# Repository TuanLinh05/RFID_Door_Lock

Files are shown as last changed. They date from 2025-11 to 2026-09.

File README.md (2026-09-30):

# 🔐 RFID Door Lock System






**🇬🇧 English** · [🇻🇳 Tiếng Việt](#tieng-viet)

A smart door lock that opens with an **RFID card** or a **keypad password**, built on an **STM32F103C8T6** with a **custom PCB**, an I²C character LCD, voice feedback and an admin menu for managing cards and passwords.

**Course project – Embedded System Design, HCM University of Technology.**
🎬 **Video demo:** [Google Drive](https://drive.google.com/drive/folders/1EJyoBcpR5TI39vi5_LgunK4Ymn7jQt8R?usp=sharing)

---

## ✨ Features

- **Two ways to unlock:** an RFID card (MFRC522, SPI) or a password on the 4×4 keypad.
- **Admin mode:** scan the admin card to change the password, add or remove cards, and view all stored cards.
- **Persistent storage:** the password and card list are saved in the STM32's **internal flash**, so they survive power loss.
- **Brute-force protection:** after 5 wrong attempts the system locks for **5 min**. It locks for **10 min** after 7 attempts and **20 min** after 9.
- **Feedback:** status on the I²C LCD and voice prompts from a **DFPlayer Mini** (granted / denied / locked / admin).
- **Relay output:** drives the electric lock (PB1) and locks again automatically after 7 s.

## 🧠 State machine

```text
IDLE ──(card / key)──▶ INPUT_PASS ──▶ ACCESS_GRANTED ──(timeout)──▶ IDLE
  │                        │
  │                        └──▶ ACCESS_DENIED ──(≥5 fails)──▶ LOCKED ──▶ IDLE
  └──(admin card)──▶ ADMIN_MENU ──▶ SET_PASS_1 → SET_PASS_2
                                 ├─▶ EDIT_CARD (add / delete)
                                 └─▶ VIEW_ALL
```

## 📂 Project structure

```text
RFID_Door_Lock/
├── Firmware/RFID_Door_Lock/   # STM32CubeIDE project
│   └── Core/
│       ├── Src/               # main.c (state machine) + CubeMX peripheral init
│       └── Lib/               # RC522, KEYPAD, LCD I2C, DFPlayer, Storage drivers
├── Hardware/                  # Altium Designer project (latest)
│   └── 01_Design/             # Schematics: MCU, POWER, RFID, LCD, Relay + PCB
├── BTL_HW_V1.0.0/             # Hardware release V1.0.0: design, 3D models, references
└── Docs/                      # Technical requirements document (PDF / DOCX)
```

## 🚀 Getting started

1. Open `Firmware/RFID_Door_Lock` in **STM32CubeIDE**, build and flash it with an ST-Link.
2. Set your admin card UID in `Core/Src/main.c`:
   ```c
   uint8_t ADMIN_UID[4] = {51, 194, 201, 27};   // replace with your card's UID
   ```
3. Copy 4 voice tracks (`0001.mp3` … `0004.mp3`: granted, denied, locked, admin) to the DFPlayer's micro-SD card.
4. Open `Hardware/01_Design/BTL_HW_V1.0.0.PrjPcb` in **Altium Designer** to view or edit the PCB.

---

## 🇻🇳 Tiếng Việt

[🇬🇧 English](#english) · **🇻🇳 Tiếng Việt**

Khóa cửa thông minh mở bằng **thẻ RFID** hoặc **mật khẩu trên bàn phím**. Hệ thống dùng **STM32F103C8T6** trên **PCB tự thiết kế**, có màn hình LCD I²C, phát âm thanh thông báo và menu quản trị để quản lý thẻ và mật khẩu.

**Bài tập lớn môn Thiết kế Hệ thống Nhúng, Trường Đại học Bách khoa – ĐHQG TP.HCM.**
🎬 **Video demo:** [Google Drive](https://drive.google.com/drive/folders/1EJyoBcpR5TI39vi5_LgunK4Ymn7jQt8R?usp=sharing)

### ✨ Tính năng

- **Hai cách mở khóa:** thẻ RFID (MFRC522, giao tiếp SPI) hoặc mật khẩu trên bàn phím 4×4.
- **Chế độ quản trị:** quét thẻ admin để đổi mật khẩu, thêm hoặc xóa thẻ, xem danh sách thẻ.
- **Lưu trữ bền vững:** mật khẩu và danh sách thẻ được lưu trong **flash nội** của STM32, không mất khi tắt nguồn.
- **Chống dò mật khẩu:** sai 5 lần thì khóa **5 phút**. Sai 7 lần khóa **10 phút**, sai 9 lần khóa **20 phút**.
- **Phản hồi:** trạng thái hiện trên LCD I²C, âm thanh từ **DFPlayer Mini** (mở cửa / từ chối / bị khóa / admin).
- **Ngõ ra relay:** điều khiển khóa điện (PB1) và tự khóa lại sau 7 giây.

Sơ đồ máy trạng thái và cấu trúc thư mục: xem phần tiếng Anh ở trên.

### 🚀 Hướng dẫn sử dụng

1. Mở `Firmware/RFID_Door_Lock` bằng **STM32CubeIDE**, build và nạp bằng ST-Link.
2. Đổi UID thẻ admin trong `Core/Src/main.c` (biến `ADMIN_UID`) thành UID thẻ của bạn.
3. Chép 4 file âm thanh (`0001.mp3` … `0004.mp3`: mở cửa, từ chối, bị khóa, admin) vào thẻ micro-SD của DFPlayer.
4. Mở `Hardware/01_Design/BTL_HW_V1.0.0.PrjPcb` bằng **Altium Designer** để xem hoặc sửa PCB.

---

<p align="center">Made by <a href="https://github.com/TuanLinh05">Vu Tuan Linh</a> · HCMUT</p>

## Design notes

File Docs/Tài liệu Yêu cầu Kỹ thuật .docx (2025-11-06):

Tài liệu Yêu cầu Kỹ thuật (Technical Requirement)

RFID_Door_Lock

1. Giới thiệu

+ Mô tả cơ bản: Hệ thống gồm 1 vi điều khiển giao tiếp với 1 RESET, 1 bàn phím, 1 relay dùng để điều khiển đóng mở cửa, 1 màn hình LCD, 1 loa thông báo, 1 mạch RFID. Hệ thống sử dụng nguồn DC 5V Adapter.

Hoạt động:
+ Khi cấp nguồn, hệ thống khởi động và hiển thị thông báo “Enter Password or Scan Card”.
+ Người dùng có thể: Nhập mật khẩu bằng bàn phím, hoặc Quẹt thẻ RFID hợp lệ để mở cửa.
+ Nếu mật khẩu hoặc thẻ hợp lệ, hệ thống: Hiển thị thông báo “Access Granted”. Phát âm thanh xác nhận.
+ Kích relay mở cửa trong thời gian định sẵn (ví dụ 5 giây).
+ Nếu nhập sai mật khẩu quá 3 lần, hệ thống sẽ: Hiển thị “System Locked – 5 Minutes”.
+ Phát âm cảnh báo qua loa. Vô hiệu hoá bàn phím trong 5 phút.

2. Requirements 2.1 Functional requirements: F-1: Hệ thống phải cho phép người dùng mở cửa bằng mật khẩu hoặc thẻ RFID hợp lệ.

F-1.1: Hệ thống đọc dữ liệu từ bàn phím ma trận (ví dụ 4×4) và nhận chuỗi số làm mật khẩu.

F-1.2: Hệ thống giao tiếp với module RFID (SPI/UART/I2C) để nhận mã thẻ.
F-1.3: Vi điều khiển so sánh mật khẩu hoặc mã RFID với dữ liệu trong EEPROM/Flash. Nếu đúng → mở cửa, nếu sai → hiển thị lỗi.

F-2: Hệ thống phải hiển thị thông tin và trạng thái hoạt động trên màn hình LCD.
F-2.1: Khi khởi động, LCD hiển thị “Enter Password or Scan Card”.
F-2.2: Khi nhập đúng, LCD hiển thị “Access Granted” trong 2 giây; khi sai, hiển thị “Wrong Password”.
F-3: Hệ thống phải có âm thanh thông báo tương ứng với từng trạng thái.
F-3.1: Khi xác thực đúng, loa phát thông báo; khi sai, phát cảnh báo.

F-4: Hệ thống phải điều khiển relay để đóng/mở cửa khi xác thực thành công.
F-4.1: Relay được kích trong 5 giây khi mở cửa; sau đó tự ngắt và trở về trạng thái chờ.
F-5: Hệ thống phải có chức năng bảo mật, giới hạn số lần nhập sai.
F-5.1: Sau 3 lần nhập sai liên tiếp, hệ thống vô hiệu hóa bàn phím 5 phút và bật cảnh báo qua loa.
F-5.2: Sau 5 phút, hệ thống tự động trở về trạng thái nhập mật khẩu ban đầu.

F-6: Hệ thống phải có khả năng đổi mật khẩu người dùng.
F-6.1: Người dùng nhấn tổ hợp phím đặc biệt (**#) để vào chế độ đổi mật khẩu. LCD hiển thị “Enter Old Password”.
F-6.2: Nếu mật khẩu cũ đúng, LCD yêu cầu nhập mật khẩu mới và xác nhận lại. Nếu trùng khớp → lưu vào EEPROM/Flash; nếu sai → báo lỗi.

F-7: Hệ thống phải hỗ trợ chế độ quản trị (Admin Mode) để quản lý thẻ RFID.
F-7.1: Khi vào chế độ Admin Mode (bằng Password_Admin hoặc thẻ master), LCD hiển thị menu: “1:Add 2:Del 3:List 4:Exit”.
F-7.2: Chức năng “Delete Card”: đọc thẻ → nếu tồn tại → xóa; nếu không → hiển thị “Not Found”.
F-7.3: Chức năng “List”: hiển thị số lượng thẻ hiện có (ví dụ “Cards: 35/50”).

F-8: Hệ thống phải lưu trữ dữ liệu bền vững.
F-8.1: Khi khởi động, hệ thống kiểm tra checksum của dữ liệu; nếu phát hiện lỗi → bỏ qua mục đó và hiển thị cảnh báo.

F-9: Hệ thống phải có nút RESET để khởi động lại toàn bộ thiết bị.

F-9.1: Khi nhấn nút RESET, toàn bộ chương trình khởi động lại và quay về trạng thái ban đầu.

F-10: Hệ thống phải hoạt động ổn định với nguồn DC 5V.

F-10.1: Vi điều khiển hoạt động ổn định trong khoảng 5V ± 5%; có mạch ổn áp và lọc nhiễu nguồn.

2.2 Non-Functional requirements:

NFR-1: Hiệu năng phản hồi: Thời gian xử lý ≤ 200 ms sau khi nhập phím hoặc quẹt thẻ.

NFR-2: An toàn dữ liệu: Dữ liệu trong EEPROM/Flash phải tồn tại sau ≥ 10⁵ chu kỳ ghi/xóa.

NFR-3: Bảo mật: Mật khẩu không hiển thị trực tiếp, chỉ hiển thị dạng ****.
NFR-4: Độ tin cậy: Tỷ lệ hoạt động đúng của hệ thống ≥ 95% sau 100 lần thử liên tiếp.

NFR-5: Khả năng phục hồi: Sau khi mất điện, hệ thống khởi động lại về trạng thái chờ mà không mất dữ liệu.

NFR-6: Thân thiện người dùng: LCD hiển thị hướng dẫn từng bước, âm thanh báo rõ ràng.

NFR-7: Giới hạn môi trường: Hoạt động trong 0–50°C, độ ẩm <85%.

NFR-8: Khả năng mở rộng: Thiết kế phần mềm theo module (Keypad, RFID, Display, EEPROM, Relay).

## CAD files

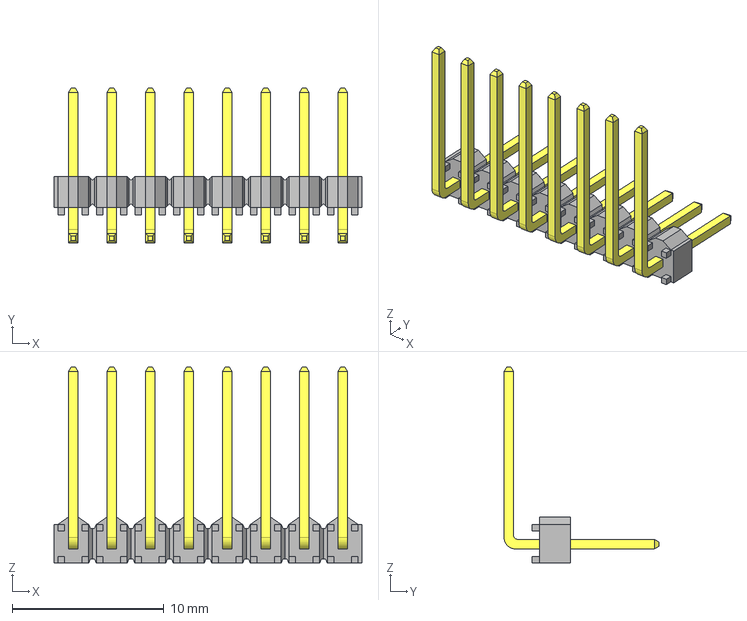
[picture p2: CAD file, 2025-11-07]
BTL_HW_V1.0.0/03_3D/TSW-108-10-S-S-RA.stp
20.3 x 10.2 x 12.9 mm
TSW-108-10-S-S-RA_body
T-1S6-10-TSW-1-10-8-RA-S

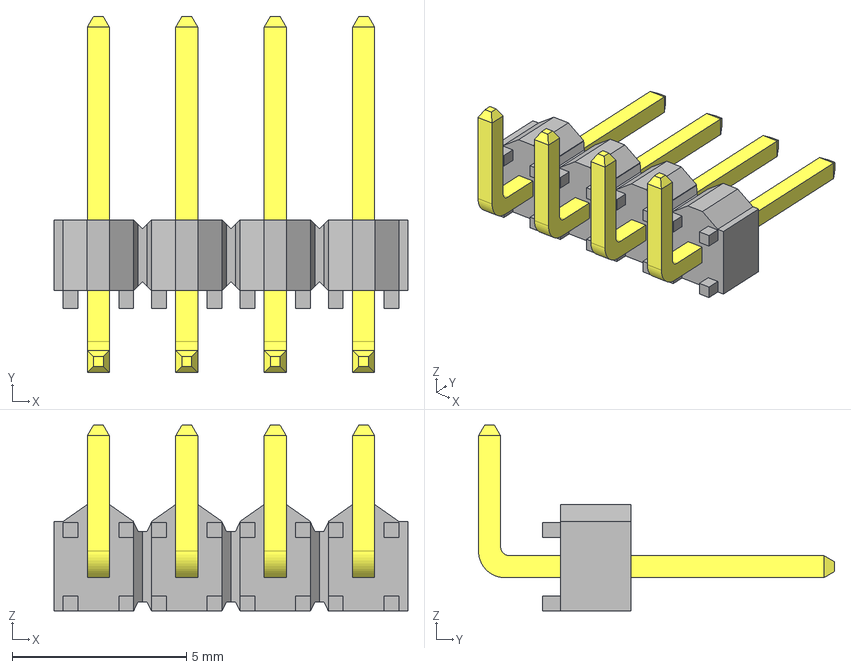
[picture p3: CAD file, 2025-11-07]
BTL_HW_V1.0.0/03_3D/HTSW-104-08-G-S-RA.stp
10.2 x 10.2 x 5.33 mm
HTSW-104-08-G-S-RA_body
T-1S6-08-HTSW-1--08-4--G-RA-S
T-1S6-08-HTSW-1--08-4--G-RA-S2

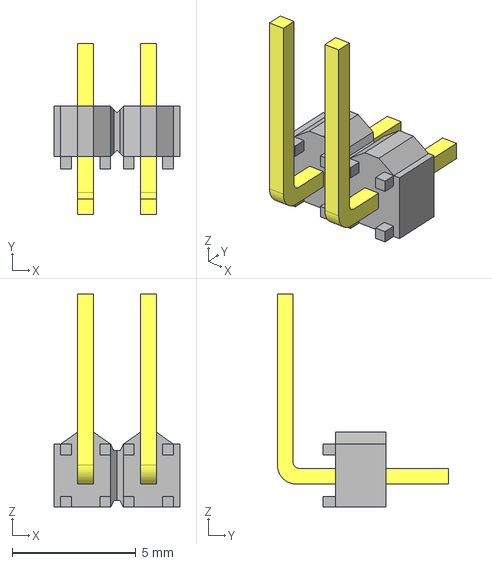
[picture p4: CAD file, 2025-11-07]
BTL_HW_V1.0.0/03_3D/MTSW-102-08-G-S-100-RA.stp
5.08 x 6.92 x 8.61 mm
MTSW-102-08-G-S-100-RA_body
MTSW-102-08-S-100-RA

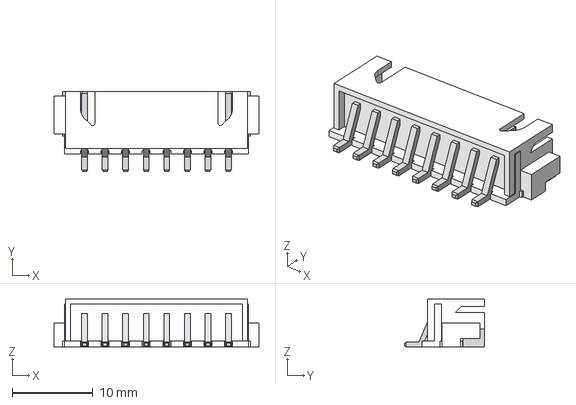
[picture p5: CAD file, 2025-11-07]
BTL_HW_V1.0.0/03_3D/JST - XH - SMD R - 8Pin - 2.54mm.stp
25.4 x 9.91 x 5.92 mm

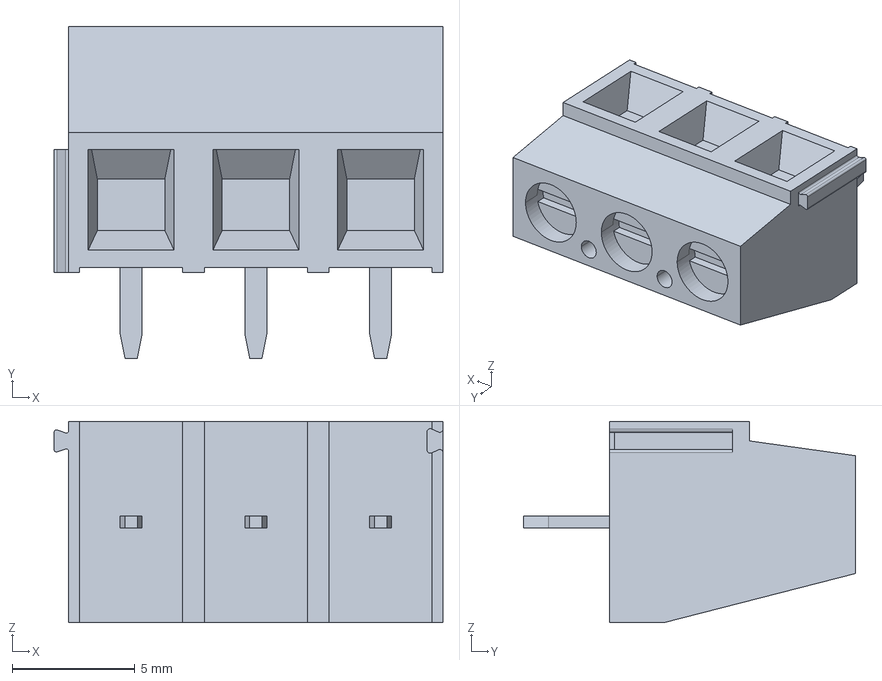
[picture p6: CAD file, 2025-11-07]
BTL_HW_V1.0.0/03_3D/282837-3--3DModel-STEP-1.STEP
15.8 x 13.5 x 8.20 mm

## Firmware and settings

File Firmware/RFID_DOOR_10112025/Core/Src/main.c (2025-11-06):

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
/* Includes ------------------------------------------------------------------*/
#include "main.h"

/* USER CODE BEGIN Includes */
#include "rc522.h"
#include "string.h"
#include "lcd.h"
#include "DFPlayer_Mini.h"
#include "keypad.h"
/* USER CODE END Includes */

/* USER CODE BEGIN PTD */
typedef enum {
    STATE_IDLE,                 // Trạng thái chờ, quét thẻ VÀ bàn phím
    STATE_ENTERING_PASSWORD,    // Trạng thái đang nhập mật khẩu
    STATE_CARD_ACCESS_GRANTED,  // Trạng thái thẻ đúng
    STATE_CARD_ACCESS_DENIED,   // Trạng thái thẻ sai
    STATE_PASS_ACCESS_GRANTED,  // Trạng thái mật khẩu đúng
    STATE_PASS_ACCESS_DENIED    // Trạng thái mật khẩu sai
} SystemState;
/* USER CODE END PTD */

/* USER CODE BEGIN PD */
#define CARD_ACCESS_DURATION    5000 // Thời gian mở cửa bằng thẻ: 5s
#define CARD_DENIED_DURATION    3000 // Thời gian báo lỗi thẻ: 3s
#define PASS_ACCESS_DURATION    4000 // Thời gian mở cửa bằng pass: 4s
#define PASS_DENIED_DURATION    3000 // Thời gian báo lỗi pass: 3s
#define PASSWORD_LENGTH         5    // Độ dài mật khẩu
/* USER CODE END PD */

I2C_HandleTypeDef hi2c2;

SPI_HandleTypeDef hspi1;

UART_HandleTypeDef huart1;
UART_HandleTypeDef huart2;

/* USER CODE BEGIN PV */
uint8_t status;
uint8_t str[MAX_LEN]; // Max_LEN = 16
uint8_t sNum[4];
uint8_t masterCardUID[4] = {4, 123, 253, 113};

volatile SystemState currentState = STATE_IDLE;
uint32_t actionTimer = 0;

const char correctPassword[PASSWORD_LENGTH + 1] = "12345"; // Mật khẩu đúng + ký tự null
char enteredPassword[PASSWORD_LENGTH + 1];
uint8_t passwordIndex = 0;
/* USER CODE END PV */

void SystemClock_Config(void);
static void MX_GPIO_Init(void);
static void MX_SPI1_Init(void);
static void MX_I2C2_Init(void);
static void MX_USART1_UART_Init(void);
static void MX_USART2_UART_Init(void);
/* USER CODE BEGIN PFP */
void display_welcome_screen(void);
void reset_password_entry(void);
/* USER CODE END PFP */

/* USER CODE BEGIN 0 */
void display_welcome_screen(void) {
    lcd_clear();
    lcd_put_cur(0, 0);
    lcd_send_string("Quet the hoac");
    lcd_put_cur(1, 0);
    lcd_send_string("nhap mat khau");
}

void reset_password_entry(void) {
    passwordIndex = 0;
    memset(enteredPassword, 0, sizeof(enteredPassword));
}
/* USER CODE END 0 */

/**
  * @brief  The application entry point.
  * @retval int
  */
int main(void)
{

  /* MCU Configuration--------------------------------------------------------*/

  /* Reset of all peripherals, Initializes the Flash interface and the Systick. */
  HAL_Init();

  /* Configure the system clock */
  SystemClock_Config();

  /* Initialize all configured peripherals */
  MX_GPIO_Init();
  MX_SPI1_Init();
  MX_I2C2_Init();
  MX_USART1_UART_Init();
  MX_USART2_UART_Init();
  /* USER CODE BEGIN 2 */
  MFRC522_Init();
  lcd_init();
  DF_Init(&huart1);


  HAL_Delay(200); // Chờ một chút để module sẵn sàng
  DF_SetVolume(25); // Đặt âm lượng (từ 0 đến 30)


  display_welcome_screen();
  /* USER CODE END 2 */

  /* Infinite loop */
  /* USER CODE BEGIN WHILE */
  while (1)
  {
    /* USER CODE END WHILE */

    /* USER CODE BEGIN 3 */
//	switch(currentState)
//	{
//		case STATE_IDLE_SCANNING:
//		{
//			// Chỉ quét thẻ khi hệ thống đang ở trạng thái chờ
//			if (MFRC522_Request(PICC_REQIDL, str) == MI_OK)
//			{
//				if (MFRC522_Anticoll(str) == MI_OK)
//				{
//					memcpy(sNum, str, 4);
//					if (memcmp(sNum, masterCardUID, 4) == 0)
//					{
//						// === THẺ ĐÚNG ===
//						// 1. Chuyển sang trạng thái Mở cửa
//						currentState = STATE_ACCESS_GRANTED;
//						// 2. Ghi lại mốc thời gian bắt đầu
//						actionTimer = HAL_GetTick();
//
//						// 3. Thực hiện hành động MỞ CỬA ngay lập tức
//						lcd_clear();
//						lcd_put_cur(0, 0);
//						lcd_send_string("The dung,");
//						lcd_put_cur(1, 2);
//						lcd_send_string("xin moi vao");
//						HAL_GPIO_WritePin(RELAY_GPIO_Port, RELAY_Pin, GPIO_PIN_SET); // Bật Relay
//					}
//					else
//					{
//						// === THẺ SAI ===
//						// 1. Chuyển sang trạng thái Báo lỗi
//						currentState = STATE_ACCESS_DENIED;
//						// 2. Ghi lại mốc thời gian bắt đầu
//						actionTimer = HAL_GetTick();
//
//						// 3. Hiển thị thông báo lỗi
//						lcd_clear();
//						lcd_put_cur(0, 4);
//						lcd_send_string("The sai!");
//					}
//				}
//			}
//			break;
//		}
//
//		case STATE_ACCESS_GRANTED:
//		{
//			// Liên tục kiểm tra xem đã đủ 3 giây chưa
//			if (HAL_GetTick() - actionTimer >= ACCESS_GRANTED_DURATION)
//			{
//				// Đã đủ 3 giây, thực hiện hành động ĐÓNG CỬA
//				HAL_GPIO_WritePin(RELAY_GPIO_Port, RELAY_Pin, GPIO_PIN_RESET); // Tắt Relay
//				display_welcome_screen(); // Hiển thị lại màn hình chờ
//				currentState = STATE_IDLE_SCANNING; // Quay về trạng thái chờ
//			}
//			break;
//		}
//
//		case STATE_ACCESS_DENIED:
//		{
//			// Liên tục kiểm tra xem đã đủ 2 giây hiển thị lỗi chưa
//			if (HAL_GetTick() - actionTimer >= ACCESS_DENIED_DURATION)
//			{
//				// Đã đủ thời gian, quay về trạng thái chờ
//				display_welcome_screen();
//				currentState = STATE_IDLE_SCANNING;
//			}
//			break;
//		}
//	} // end switch

//		switch(currentState)
//		{
//			case STATE_IDLE_SCANNING:
//			{
//				if (MFRC522_Request(PICC_REQIDL, str) == MI_OK)
//				{
//					if (MFRC522_Anticoll(str) == MI_OK)
//					{
//						memcpy(sNum, str, 4);
//						if (memcmp(sNum, masterCardUID, 4) == 0)
//						{
//							// === THẺ ĐÚNG ===
//							currentState = STATE_ACCESS_GRANTED;
//							actionTimer = HAL_GetTick();
//
//							lcd_clear();
//							lcd_put_cur(0, 0);
//							lcd_send_string("The dung,");
//							lcd_put_cur(1, 2);
//							lcd_send_string("xin moi vao");
//							HAL_GPIO_WritePin(RELAY_GPIO_Port, RELAY_Pin, GPIO_PIN_SET);
//							DF_Play(1); // <-- PHÁT FILE 0001.mp3
//						}
//						else
//						{
//							// === THẺ SAI ===
//							currentState = STATE_ACCESS_DENIED;
//							actionTimer = HAL_GetTick();
//
//							lcd_clear();
//							lcd_put_cur(0, 4);
//							lcd_send_string("The sai!");
//							DF_Play(2); // <-- PHÁT FILE 0002.mp3
//						}
//					}
//				}
//				break;
//			}
//
//			case STATE_ACCESS_GRANTED:
//			{
//				if (HAL_GetTick() - actionTimer >= ACCESS_GRANTED_DURATION)
//				{
//					HAL_GPIO_WritePin(RELAY_GPIO_Port, RELAY_Pin, GPIO_PIN_RESET);
//					display_welcome_screen();
//					currentState = STATE_IDLE_SCANNING;
//				}
//				break;
//			}
//
//			case STATE_ACCESS_DENIED:
//			{
//				if (HAL_GetTick() - actionTimer >= ACCESS_DENIED_DURATION)
//				{
//					display_welcome_screen();
//					currentState = STATE_IDLE_SCANNING;
//				}
//				break;
//			}
//		} // end switch
//
//  }

	  switch(currentState)
	  	{
	  		case STATE_IDLE:
	  		{
	  			// ---- Ưu tiên 1: Quét thẻ ----
	  			if (MFRC522_Request(PICC_REQIDL, str) == MI_OK)
	  			{
	  				if (MFRC522_Anticoll(str) == MI_OK)
	  				{
	  					// Kêu bíp báo hiệu nhận thẻ
	  					HAL_GPIO_WritePin(BUZZER_GPIO_Port, BUZZER_Pin, GPIO_PIN_SET); HAL_Delay(50);
	  					HAL_GPIO_WritePin(BUZZER_GPIO_Port, BUZZER_Pin, GPIO_PIN_RESET);

	  					memcpy(sNum, str, 4);
	  					if (memcmp(sNum, masterCardUID, 4) == 0)
	  					{
	  						currentState = STATE_CARD_ACCESS_GRANTED;
	  						actionTimer = HAL_GetTick();
	  						lcd_clear();
	  						lcd_put_cur(0, 0); lcd_send_string("The dung,");
	  						lcd_put_cur(1, 2); lcd_send_string("xin moi vao");
	  						HAL_GPIO_WritePin(RELAY_GPIO_Port, RELAY_Pin, GPIO_PIN_SET);
	  						DF_Play(1); // Phát âm thanh thẻ đúng
	  					}
	  					else
	  					{
	  						currentState = STATE_CARD_ACCESS_DENIED;
	  						actionTimer = HAL_GetTick();
	  						lcd_clear();
	  						lcd_put_cur(0, 4); lcd_send_string("The sai!");
	  						DF_Play(2); // Phát âm thanh thẻ sai
	  					}
	  				}
	  			}

	  			// ---- Ưu tiên 2: Quét bàn phím ----
	  			char key = Keypad_Get_Pressed_Key();
	  			if (key != '\0') // Nếu có phím được nhấn
	  			{
	  				// Kêu bíp báo hiệu nhấn phím
	  				HAL_GPIO_WritePin(BUZZER_GPIO_Port, BUZZER_Pin, GPIO_PIN_SET); HAL_Delay(50);
	  				HAL_GPIO_WritePin(BUZZER_GPIO_Port, BUZZER_Pin, GPIO_PIN_RESET);

	  				// Nếu là một chữ số thì bắt đầu nhập mật khẩu
	  				if (key >= '0' && key <= '9')
	  				{
	  					currentState = STATE_ENTERING_PASSWORD;
	  					reset_password_entry();
	  					enteredPassword[passwordIndex++] = key;

	  					lcd_clear();
	  					lcd_put_cur(0, 0); lcd_send_string("Mat khau la:");
	  					lcd_put_cur(1, 0); lcd_send_string("*");
	  				}
	  			}
	  			break;
	  		}

	  		case STATE_ENTERING_PASSWORD:
	  		{
	  			// Vô hiệu hóa quét thẻ khi đang nhập pass
	  			char key = Keypad_Get_Pressed_Key();

	  			// Chỉ chấp nhận các phím số
	  			if (key != '\0' && (key >= '0' && key <= '9'))
	  			{
	  				// Kêu bíp báo hiệu nhấn phím
	  				HAL_GPIO_WritePin(BUZZER_GPIO_Port, BUZZER_Pin, GPIO_PIN_SET); HAL_Delay(50);
	  				HAL_GPIO_WritePin(BUZZER_GPIO_Port, BUZZER_Pin, GPIO_PIN_RESET);

	  				if (passwordIndex < PASSWORD_LENGTH)
	  				{
	  					enteredPassword[passwordIndex++] = key;
	  					// Hiển thị '*'
	  					lcd_put_cur(1, passwordIndex - 1);
	  					lcd_send_data('*');
	  				}

	  				// Khi đã đủ 5 ký tự
	  				if (passwordIndex == PASSWORD_LENGTH)
	  				{
	  					if (strcmp(enteredPassword, correctPassword) == 0)
	  					{
	  						currentState = STATE_PASS_ACCESS_GRANTED;
	  						actionTimer = HAL_GetTick();
	  						lcd_clear();
	  						lcd_put_cur(0, 0); lcd_send_string("Mat khau chinh xac");
	  						lcd_put_cur(1, 2); lcd_send_string("Xin moi vao");
	  						HAL_GPIO_WritePin(RELAY_GPIO_Port, RELAY_Pin, GPIO_PIN_SET);
	  						DF_Play(3); // Phát âm thanh pass đúng
	  					}
	  					else
	  					{
	  						currentState = STATE_PASS_ACCESS_DENIED;
	  						actionTimer = HAL_GetTick();
	  						lcd_clear();
	  						lcd_put_cur(0, 0); lcd_send_string("Mat khau sai,");
	  						lcd_put_cur(1, 0); lcd_send_string("xin hay nhap lai");
	  						DF_Play(4); // Phát âm thanh pass sai
	  					}
	  				}
	  			}
	  			break;
	  		}

	  		case STATE_CARD_ACCESS_GRANTED:
	  		{
	  			if (HAL_GetTick() - actionTimer >= CARD_ACCESS_DURATION) {
	  				HAL_GPIO_WritePin(RELAY_GPIO_Port, RELAY_Pin, GPIO_PIN_RESET);
	  				display_welcome_screen();
	  				currentState = STATE_IDLE;
	  			}
	  			break;
	  		}
	  		case STATE_CARD_ACCESS_DENIED:
	  		{
	  			if (HAL_GetTick() - actionTimer >= CARD_DENIED_DURATION) {
	  				display_welcome_screen();
	  				currentState = STATE_IDLE;
	  			}
	  			break;
	  		}
	  		case STATE_PASS_ACCESS_GRANTED:
	  		{
	  			if (HAL_GetTick() - actionTimer >= PASS_ACCESS_DURATION) {
	  				HAL_GPIO_WritePin(RELAY_GPIO_Port, RELAY_Pin, GPIO_PIN_RESET);
	  				display_welcome_screen();
	  				currentState = STATE_IDLE;
	  			}
	  			break;
	  		}
	  		case STATE_PASS_ACCESS_DENIED:
	  		{
	  			if (HAL_GetTick() - actionTimer >= PASS_DENIED_DURATION) {
	  				display_welcome_screen();
	  				currentState = STATE_IDLE;
	  			}
	  			break;
	  		}
	  	} // end switch
  }
  /* USER CODE END 3 */
}

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


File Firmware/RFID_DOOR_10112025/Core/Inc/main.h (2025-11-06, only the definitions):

#define SDA_Pin GPIO_PIN_4
#define SDA_GPIO_Port GPIOA
#define RST_Pin GPIO_PIN_0
#define RST_GPIO_Port GPIOB
#define ROW_1_Pin GPIO_PIN_12
#define ROW_1_GPIO_Port GPIOB
#define ROW_2_Pin GPIO_PIN_13
#define ROW_2_GPIO_Port GPIOB
#define ROW_3_Pin GPIO_PIN_14
#define ROW_3_GPIO_Port GPIOB
#define ROW_4_Pin GPIO_PIN_15
#define ROW_4_GPIO_Port GPIOB
#define COL_1_Pin GPIO_PIN_8
#define COL_1_GPIO_Port GPIOA
#define COL_2_Pin GPIO_PIN_9
#define COL_2_GPIO_Port GPIOA
#define COL_3_Pin GPIO_PIN_10
#define COL_3_GPIO_Port GPIOA
#define COL_4_Pin GPIO_PIN_11
#define COL_4_GPIO_Port GPIOA
#define RELAY_Pin GPIO_PIN_4
#define RELAY_GPIO_Port GPIOB
#define BUZZER_Pin GPIO_PIN_5
#define BUZZER_GPIO_Port GPIOB

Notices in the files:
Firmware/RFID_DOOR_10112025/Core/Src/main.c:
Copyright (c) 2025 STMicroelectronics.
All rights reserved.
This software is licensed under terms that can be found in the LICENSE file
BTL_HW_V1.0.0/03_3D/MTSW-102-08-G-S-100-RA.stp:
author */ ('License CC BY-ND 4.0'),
